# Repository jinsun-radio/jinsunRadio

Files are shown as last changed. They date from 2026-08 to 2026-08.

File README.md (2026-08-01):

# jinsun-radio（金孫收音機）

給獨居與失能長者的近端 AI 陪伴與社區互助派遣系統。

以長輩熟悉的收音機作為入口，打開、按下、說話——零學習成本。平常資料在地處理、不監控、不上雲；只有主動求助或授權週報才啟用 ASR／LLM／TTS。當長者提出需求或發生緊急狀況，系統會通知家人並媒合附近志工、物業、照服員，以時間銀行回饋，形成可追蹤、可派遣、可回報的照顧閉環。

> 一句話定位：不是讓長輩學會用 App，而是讓 AI 長得像他本來就會用的收音機。

2026 AI 創新獎・組別二：智慧照護與居家健康（Smart Care & Home Health）參賽提案。

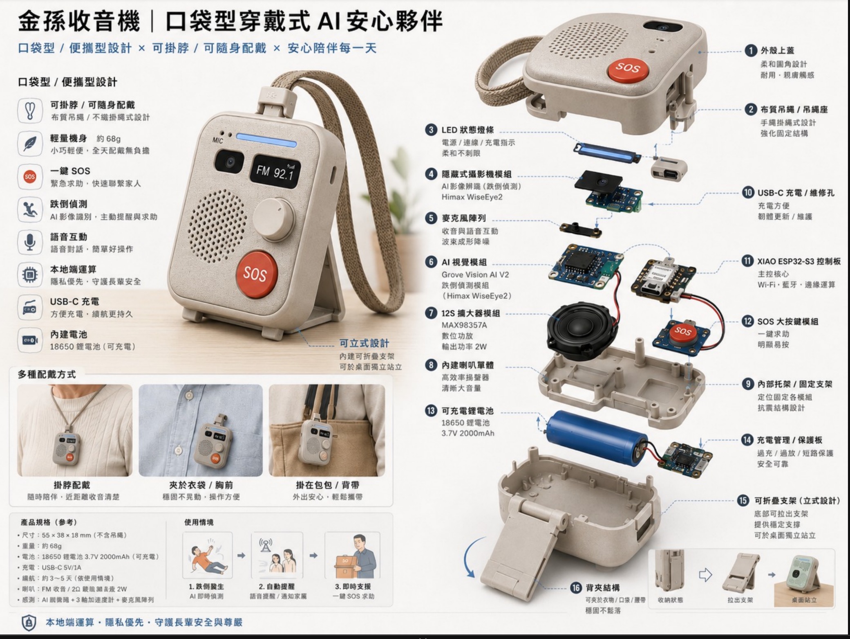
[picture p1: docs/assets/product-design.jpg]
金孫收音機｜口袋型穿戴式 AI 安心夥伴


> ⚠️ 硬體型態迭代中：目前有兩個版本的設計圖並存——`docs/assets/system-architecture.jpg`（桌上型收音機，主控為 Realtek AmebaPro2）與上圖（口袋型穿戴式，主控為 XIAO ESP32-S3）。以哪個為準尚待確認，見下方「技術架構」。

## 核心場景

- **大按鈕 SOS**：一按直接求助，不必解鎖打字
- **跌倒／久臥偵測**：近端視覺＋麥克風陣列偵測異常，語音確認「有沒有撞到？」
- **語音求助／代辦**：長輩以自然語言（含台語）說出需求，如「我想買牛奶跟雞蛋」
- **吃藥／復健提醒**：可由兒女預先錄音
- **安心週報**：授權後由 AI 摘要活動、提醒、異常、互動狀況
- **社區派遣**：偵測到緊急狀況 → 通知監護人 → 派送附近志工／物業／照服員 → 回報 ETA → 到場回報「已安全」

## 角色與軟體類型

| 角色 | 需要看到／做到什麼 | 軟體類型 |
|---|---|---|
| 長輩 | 不需要 App，只需要收音機：跌倒偵測相機＋聲音偵測＋語音播報（是否需要幫助／還有多久會到）＋ SOS 時 TTS | 嵌入式裝置，零學習成本 |
| 家屬 | 掌握老人家即時狀態、接收緊急通知 | Flutter App（跨 Android／iOS） |
| 志工 | 看到老人家需要什麼物資、接單去採買／到場確認安全 | Flutter App |
| 管理介面後台（社工／我們） | 所有長輩即時狀態的 dashboard，需可匯出 Excel 以符合政府申報需求 | Web（App 亦可） |

## 技術架構：感知 → 決策 → 行動 → 回報

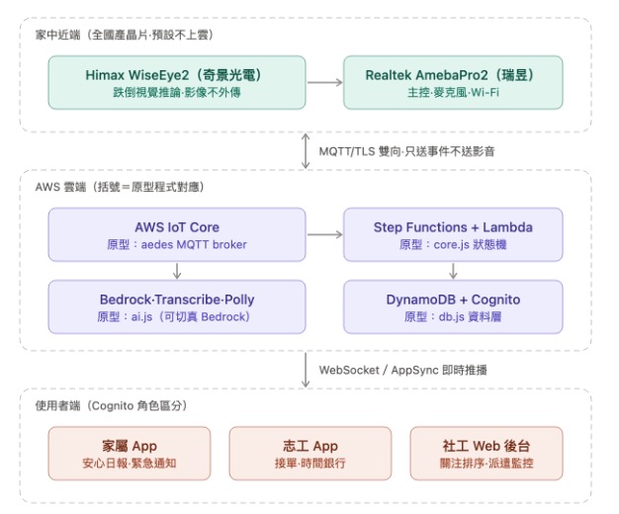
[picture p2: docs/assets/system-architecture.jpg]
系統架構圖


- **感知層（長輩端裝置，全國產晶片，預設不上雲）**：Himax WiseEye2（奇景光電，跌倒視覺推論，透過 Grove Vision AI V2／XIAO ESP32-S3 兩種硬體型態都在評估中，見上方警示）＋麥克風陣列；裝置與雲端之間僅透過 MQTT/TLS 傳送事件，不傳影音
- **決策層（AWS 雲端）**：AWS IoT Core 接事件 → Step Functions + Lambda 做事件分級與逾時升級判斷 → Bedrock／Transcribe／Polly 處理 ASR／LLM／TTS → DynamoDB + Cognito 做資料層與角色權限
- **行動層**：裝置端語音對講與安撫回應（「已經幫你叫人，預計 6 分鐘內到」）＋透過 WebSocket／AppSync 即時推播給家屬 App／志工 App／社工 Web 後台，媒合志工到場確認安全（Physical AI in the Loop，類似 Uber 的派工與 ETA 回報）

完整架構圖與跌倒偵測事件流程（sequence diagram）見 [`docs/architecture.md`](docs/architecture.md)。

技術落地路線：Himax WiseEye2 → 延伸至 Kneron + Andes RISC-V 國產邊緣 AI 生態。

## 隱私與資安設計

| 模式 | 運作 | 內容 |
|---|---|---|
| 平常模式 | 近端運作 | 提醒、關鍵字偵測、跌倒判斷；原始影音不上雲 |
| 主動模式 | 需要時才上雲 | 求助、叫人、家屬授權週報；ASR／LLM／TTS 處理 |
| 對講模式 | 可被看見、可被拒絕 | 家人不能偷聽；長輩可說「好」或「不要」 |

設計底線：長輩永遠知道自己何時被連線、何時被求助、資料何時離開家。

## 硬體規格（口袋型穿戴版本，參考）

| 項目 | 規格 |
|---|---|
| 尺寸 | 55 × 38 × 18 mm（不含吊繩） |
| 重量 | 約 68g |
| 電池 | 18650 鋰電池 3.7V 2000mAh（可充電） |
| 充電 | USB-C 5V/1A |
| 續航 | 約 3–5 天（依使用情境） |
| 喇叭 | FM 收音，輸出功率 2W |
| 感測 | AI 視覺辨識（跌倒偵測）＋ 3 軸加速度計 ＋ 麥克風陣列 |
| 配戴方式 | 掛脖、夾於衣物／口袋、掛包包背帶；內建可折疊支架可桌面立式擺放 |

主要模組：外殼上蓋、布質吊繩、LED 狀態燈條、隱藏式攝影機模組（Himax WiseEye2 跌倒視覺辨識）、麥克風陣列、Grove Vision AI V2 視覺模組、MAX98357A 數位功放、內建喇叭、XIAO ESP32-S3 控制板（主控／Wi-Fi／藍牙／邊緣運算）、SOS 大按鍵模組、可充電鋰電池與充電保護板、可折疊立式支架、背夾結構。完整零件圖見上方產品外觀圖。

## Repo 結構

```
jinsun-radio/
├── docs/           系統架構、事件流程圖
├── firmware/       長輩端裝置韌體（Himax WiseEye2 + Realtek AmebaPro2）
├── cloud/          雲端後端（AWS IoT Core / Step Functions / Bedrock / DynamoDB）
├── apps/
│   ├── family_app/     家屬 App（Flutter）
│   └── volunteer_app/  志工 App（Flutter）
└── admin/          管理介面後台（社工 Web dashboard）
```

## 快速啟動（Phase 1 薄閉環 demo）

三端皆為 Flutter 專案，資料層為 `jinsun_core` 的 `MockBackend`（in-app mock，無真後端）。iOS／Android 工具鏈尚未備齊時，用 `-d chrome` 或 `-d macos` 即可跑。

```bash
# 家屬 App
cd apps/family_app && flutter pub get && flutter run -d chrome

# 志工 App
cd apps/volunteer_app && flutter pub get && flutter run -d chrome

# 社工後台（web，含下載 Excel）
cd admin && flutter pub get && flutter run -d chrome

# 核心狀態機測試（20 秒升級、派遣生命週期、點數）
cd apps/packages/core && flutter test
```

開啟後按右下角「模擬收音機」觸發事件：
- **疑似跌倒** → 20 秒未回應自動升級 → 通知＋開派遣單（家屬端有虛擬志工自動接單回 ETA）
- **SOS** → 立即開緊急派遣單
- **物資需求** → 志工端可接單採買、回報送達

各端功能與範圍見子專案 README；spec 與拍板決策見 [`docs/requirements/phase1-mvp.md`](docs/requirements/phase1-mvp.md)。

## 專案狀態

Phase 1 薄閉環已實作（2026-07-11）：`jinsun_core` 狀態機＋家屬／志工／社工三端可跑、有測試。`cloud/` 與 `firmware/` 尚未動工，三端目前各自獨立模擬（跨裝置同步待 Phase 2 真後端）。詳細背景與完整企劃書內容請見團隊內部文件。

技術落地路線圖（Phase 1–4）：
1. Web／PWA ＋ 收音機外殼 mockup（服務閉環可展示）
2. Himax WiseEye2 近端影像／語音偵測驗證
3. 串接社區物業、照服單位、地方政府、時間銀行
4. 導入獨居老人服務、關懷據點、銀髮宅、智慧社區

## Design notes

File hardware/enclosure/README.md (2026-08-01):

# 長輩端收音機外殼（HUB8735 Ultra smart speaker enclosure）

長輩端裝置的實體外殼：參數化 CAD 原始碼（build123d / Python）＋可直接列印的 STL / 3MF。
韌體在 `firmware/`，硬體與雲端的整合契約在 `docs/requirements/hardware-integration.md`。

外形：直立式圓潤方塊，外徑約 **96 × 115.5 × 56 mm**（W × H × D，含磁吸背板與立架翻片），
單位一律 mm。世界座標：+X 右（正面視角）、+Y 向後、+Z 上；原點 X 置中、Z=0 在外底面、
正面外表面在 Y=−23。

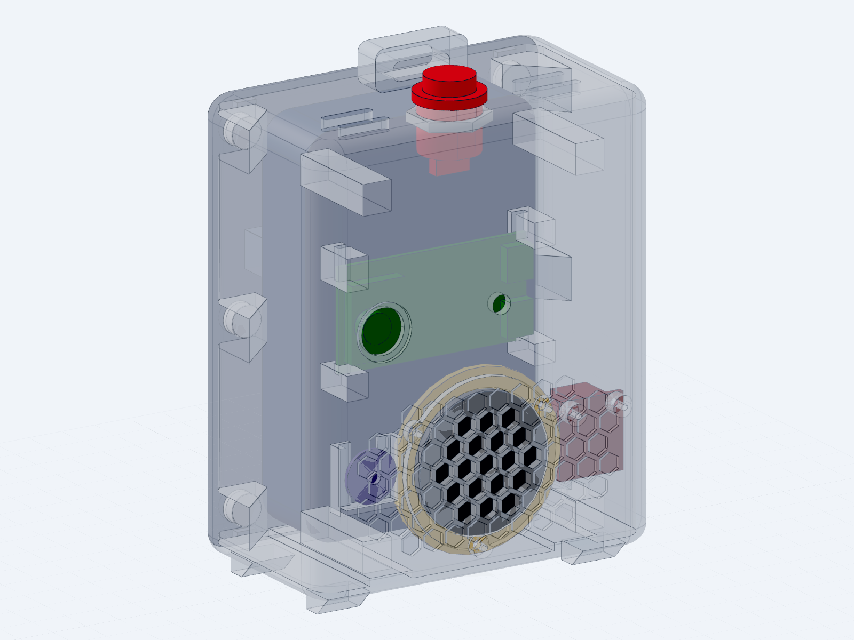
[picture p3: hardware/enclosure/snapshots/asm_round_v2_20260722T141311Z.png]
組裝件


## 檔案結構

```
hardware/enclosure/
├── speaker_design.py                參數與全部零件的 make_*() 幾何（唯一 source of truth）
├── hub8735_speaker_assembly.py      完整標註組裝件（含 mating datums）
├── shell_print.py                   列印件：主殼
├── back_panel_print.py              列印件：磁吸背板
├── speaker_clamp_print.py           列印件：喇叭壓環
├── stand_flap_print.py              列印件：折疊立架／背夾
├── assembly_test.py                 干涉與置入路徑稽核（改版後必跑）
├── *.step                           上列各 .py 產生的 STEP（交付物，進版控）
├── print/                           切片用 STL / 3MF
├── snapshots/                       定版設計截圖
└── reference/speaker-grille.stl     正面蜂巢格柵的造型參考件
```

**只改 `.py`，不要手改 `.step`。** `.step` / `print/*` 都是由 `.py` 產生的輸出。

## 五個列印件

| 檔案 | 說明 | 列印方向 / 材料 |
|---|---|---|
| `shell_print` | 主殼：正面蜂巢格柵、相機窗、喇叭座、麥克風通道、擴大機柱、行動電源導軌、頂部按鈕孔與背帶橋 | 正面朝下貼床（切片前繞 X 轉 −90°），內部特徵全部往上長 |
| `back_panel_print` | 磁吸背板：6 顆磁鐵、4 條對位唇、立架鉸鏈耳座 | 外面朝下貼床（唇朝上） |
| `speaker_clamp_print` | 喇叭壓環，壓住 36 mm 喇叭法蘭 | 平放；3× M2×5 **沉頭**自攻螺絲鎖進殼體柱 |
| `stand_flap_print` | 折疊立架／背夾，鉸接在背板上（Ø3 卡榫扣進耳座），開到 ~35° 讓機身後仰 ~12° | 平放（外面朝下）；**建議 PETG**，夾持需要彈性 |
| `hub8735_speaker_assembly` | 不列印，是驗證與展示用的完整組裝件 | — |

## 內部元件（尺寸皆為實測／查證，非估計）

- **HUB8735 Ultra**：53 × 27 mm PCB、模組厚 8.8 mm。側裝（53 mm 橫置），PCB 平行正面牆，
  鏡頭穿過正面 Ø17 窗。板子由上往下滑入兩支 C 形溝槽塔，**只夾四個短邊角**（長邊有焊排）。
  USB-C 朝 +X，內部留約 28 mm 插頭空間。板背若插排針，與行動電源僅剩約 0.9 mm——
  **杜邦母頭裝不下，要焊線或用直角接頭**。
- **喇叭**：Ø36 ±0.4 / 深 17 ±0.5 / 法蘭 2.7 ±0.3，3 W 4 Ω。淺座環定位 ＋ 壓環固定。
- **麥克風**：INMP441 breakout（**圓形 Ø14**），貼正面牆的 C 形凹槽，Ø3 導音孔穿牆（底進音 MEMS）。
- **擴大機**：GY-MAX98357A（18 × 20，上緣端子台），鎖在兩支 M2 柱上（間距 13 mm，**實板需複驗**），元件面朝後。
- **行動電源**：MD-BP075-Qi，104 × 65 × 19.5 mm、約 200 g、10000 mAh。直立靠背板，
  由地軌＋前擋柱＋磁鐵柱內面定位，拆背板即可更換；底部留充電線槽。
- **按鈕**：16 mm 防水鈕，M16×1.0、body flats 15.0、帽 Ø13、全長 24.8。頂板孔 Ø16.2 帶 15.2 防轉平邊。
- **磁吸背板**：12 顆 Ø8×3 圓磁（殼側 6 顆凹陷 0.8、板側 6 顆凸出 0.8，互相自動對位）。
  **磁鐵要黏牢，且注意極性。**

BOM 五金：3× M2×5 沉頭自攻（喇叭壓環）、2× M2 自攻（擴大機）、12× Ø8×3 圓磁鐵、
16 mm 按鈕 ×1、背帶織帶（頂部 16 × 5 穿帶孔）。

## 幾個不能亂動的設計約束

改幾何前先讀這幾條，都是 `assembly_test.py` 的置入路徑掃掠稽核逼出來的：

1. **只夾三角**：右上角不能有夾塊，否則抽板時卡住 USB-C 凸出。
2. **上排夾塊止於 Z 82.5**：再高則板子由上往下放不進去（頂到天花板）。
3. **左上夾塊內面 −34.6**：讓出相機模組的掃掠通道。
4. **行動電源左上擋點是天花板懸吊的 45° 倒角肋（Y ≥ −4.5）**，不能改成正面牆立柱——會擋住板子的抽出路徑；右上維持立柱。
5. **頂部圓角 ≤ 6**（≥7 會破到內部天花板角落）；喇叭壓環在 X=−22.2 有一段平邊讓開麥克風通道。
6. **格柵底孔要停在凹槽底面下方 ≥1 mm**，否則正面會穿孔。
7. 背板對位唇貼在腔體地板／天花板的 X 34–42.9（貼側牆會撞到後腔圓角）。

**任何佈局改動後都要重跑 `assembly_test.py`。**

## 工具鏈設定

CAD 技能（`cad` / `cad-viewer` / `gcode` 等）已 vendored 在 repo 根目錄的 `.agents/skills/`，
版本鎖在 `skills-lock.json`。Python 環境不進版控，第一次要自己建：

```bash
# 在 repo root
uv venv --python 3.12 .venv          # 或 python3.12 -m venv .venv
.venv/bin/pip install -r .agents/skills/cad/requirements.txt   # cadpy(editable) + playwright
.venv/bin/python -m playwright install chromium --only-shell   # snapshot 需要
```

已驗證版本：Python 3.12、build123d 0.11.1。

## 常用指令

在 `hardware/enclosure/` 底下執行（路徑是相對於 cwd 解析的）：

```bash
R=../..   # repo root

# 由 .py 重新產生 STEP（＋viewer 用的 GLB 快取）
$R/.venv/bin/python $R/.agents/skills/cad/scripts/step shell_print.py
$R/.venv/bin/python $R/.agents/skills/cad/scripts/step hub8735_speaker_assembly.py

# 匯出切片用 mesh
$R/.venv/bin/python $R/.agents/skills/cad/scripts/step shell_print.py --stl print/shell_print.stl

# 幾何檢查
$R/.venv/bin/python $R/.agents/skills/cad/scripts/inspect refs shell_print.step --facts --planes --positioning

# 視覺檢查（--job 批次模式會靜默失敗，一次只跑一個 --input/--output）
$R/.venv/bin/python $R/.agents/skills/cad/scripts/snapshot --input shell_print.step --output snapshots/shell.png

# 干涉／置入路徑稽核
$R/.venv/bin/python assembly_test.py

# 3D viewer（預設 port 4178）
node $R/.agents/skills/cad-viewer/scripts/viewer/backend/server.mjs
```

完整設計歷程與中間迭代截圖留在原始 CAD repo（`../cad`，`hub8735_speaker/`），這裡只保留定版。

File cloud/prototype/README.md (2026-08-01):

# cloud/prototype · 語音多 Agent server（本地原型）

硬體只做「喚醒 + 錄音 + ASR → 文字」；**所有意圖判斷、對話、急救與需求決策都在這個 server**。
設計成介面可直接切換成 AWS 服務（見 [`../../docs/architecture.md`](../../docs/architecture.md)、
[`../../docs/requirements/voice-agent-server.md`](../../docs/requirements/voice-agent-server.md)）。

## 資料流

```
硬體(喚醒+ASR) → POST /voice {device_serial,text}
      → Orchestrator
         ├─ 急救對話進行中？ → Emergency Agent（吃掉「我沒事」/後續回應）
         ├─ Intent Agent 分類（rule 快路徑優先，未命中才問 Bedrock）
         │    emergency → Emergency Agent（逾時階梯 → 升級派遣）
         │    need      → Needs Agent（建 supply 派遣單）
         │    device    → Device Agent（音量/停止…）
         │    general   → Conversation Agent（帶 Memory）
         └─ Response Generator → { reply, intent, action }
      → 硬體 TTS 播 reply；action.command 由硬體執行
```

Emergency / Needs 的決策會寫進既有 Supabase（`radio_events` + `dispatch_tasks`），
**自動觸發家屬 App／志工 App／社工後台的即時推播**——不另建通知系統。

## 跑起來（零設定、離線可跑）

```bash
cd cloud/prototype
npm test          # 黃金時間鏈路合約測試（假計時器，秒過）
npm start         # 啟動 server（預設 mock LLM + dry-run 派遣）

curl -s localhost:8787/voice -d '{"device_serial":"JS-0001","text":"我跌倒了"}'
curl -s localhost:8787/voice -d '{"device_serial":"JS-0001","text":"我想買牛奶跟雞蛋"}'
```

不填任何金鑰時：LLM 走 mock（規則化回覆）、派遣走 dry-run（印 log），狀態機與測試照跑。

## 端到端測試：硬體發聲 → server → 三端亮起

目標：證明「裝置上報 → server 處理 → 寫進 Supabase → 家屬/志工/社工三端即時亮」整條通。

**關鍵前提**：server 要用 Supabase **SERVICE key**（secret，非 anon）才寫得進 `dispatch_tasks`。
用 anon key 只能寫 `radio_events`、寫不了派遣單 → 志工端不會出現接單。

```bash
cd cloud/prototype
npm i @supabase/supabase-js          # 讓 dispatch 能真的寫 Supabase

# 終端 A：啟動 server（填 service key → 啟動日誌要顯示 dispatch=live）
SUPABASE_SERVICE_KEY=<你的-service-key> EMERGENCY_WAIT1_MS=4000 EMERGENCY_WAIT2_MS=4000 npm start

# 終端 B：即時盯著 Supabase（不用開三個 App 也能確認寫進去了）
npm run watch
```

然後**模擬硬體**（或用真裝置對 `/voice` 發同樣的請求）：

```bash
# ① 實體 SOS 鍵 → 立即升級（終端 B 會馬上冒出 sos/escalated + emergency 待接單，長輩轉🔴）
curl -s localhost:8787/voice -d '{"device_serial":"JS-0001","event":"sos"}'

# ② 語音「我跌倒了」→ 問診 → 沒回應 → 約 8 秒後升級（用上面的 WAIT 環境變數縮短）
curl -s localhost:8787/voice -d '{"device_serial":"JS-0001","text":"我跌倒了"}'

# ③ 物資需求「我想買牛奶跟雞蛋」→ 立即出現 supply 待接單
curl -s localhost:8787/voice -d '{"device_serial":"JS-0001","text":"我想買牛奶跟雞蛋"}'
```

**驗收點**：
1. `npm run watch` 的「最新事件／派遣單」冒出新列、長輩燈號變色 → **server→Supabase 通**。
2. 打開家屬 App（該長輩收到緊急通知）、志工 App（出現待接單）、社工後台（dashboard 轉🔴）
   → **Supabase→三端推播通**。
3. 真裝置測下行：裝置訂閱 `jinsun/JS-0001/cmd`，急救逾時後應收到 speak 指令並發聲。
   瀏覽器模擬控制台仍走 `GET /commands` 長輪詢（enqueue 扇出，兩通道都會收到同一筆指令）。
   broker 有兩種型態，看 `/health` 的 `mqtt` 欄位確認目前模式：

   | 模式 | 怎麼啟動 | 裝置／對測連哪 |
   |---|---|---|
   | `live`（內嵌 aedes，本機開發） | `npm start`（預設，`MQTT_PORT` 可改埠、`0`＝停用） | `mosquitto_sub -h <server IP> -t 'jinsun/JS-0001/cmd' -v` |
   | `client`（外部 broker，Render 部署） | `MQTT_URL=mqtts://mqttgo.io:8883 npm start` | `mosquitto_sub -h mqttgo.io -t 'jinsun/JS-0001/cmd' -v` |

   Render 這類 PaaS 只對外開 HTTPS(443)，內嵌 broker 的 1883 從公網進不來，所以改設 `MQTT_URL`
   讓 server 與裝置各自連上同一顆外部 broker 會合（topic／payload／QoS 契約完全相同）。
   沒裝 mosquitto 的話 `npx mqtt sub …` 等效。

> `device_serial` 要用資料庫既有的 `JS-0001/JS-0002/JS-0003`（seed 已綁 elder-1/2/3），
> 否則 trigger 反查不到 elder_id。

## 接真服務

複製 `.env.example` 為 `.env` 並填：

- `LLM_PROVIDER=bedrock` + AWS 憑證 → Intent/Needs/Conversation 走真 Amazon Bedrock（Claude）。
  需 `npm i @aws-sdk/client-bedrock-runtime`。
- `SUPABASE_SERVICE_KEY=...` → Emergency/Needs 真的寫派遣單、觸發三端推播。
  需 `npm i @supabase/supabase-js`。

## 檔案

| 檔 | 職責 | 正式對應 |
|---|---|---|
| `src/config/triggers.js` | **喚醒詞／急救詞／需求詞／裝置詞＋急救對話腳本與逾時階梯**（寫死在 server） | Lambda 設定／參數表 |
| `src/agents/intent.js` | 意圖分類（rule + LLM） | Bedrock |
| `src/agents/emergency.js` | 急救對話狀態機（黃金時間鏈路） | Step Functions |
| `src/agents/needs.js` | 需求解析 → 物資派遣單 | Bedrock + Step Functions |
| `src/agents/conversation.js` | 陪伴聊天（帶記憶） | Bedrock |
| `src/agents/device.js` | 裝置控制指令 | IoT Core 下發 |
| `src/agents/memory.js` | 長期記憶 | DynamoDB |
| `src/llm/bedrock.js` | LLM 可切換介面（mock/bedrock） | Bedrock Runtime |
| `src/dispatch.js` | 寫 Supabase 觸發三端 | Step Functions + AppSync |
| `src/orchestrator.js` | 路由大腦 | — |
| `src/server.js` | HTTP 入口 | API Gateway + Lambda |

> ⚠️ 改動 `triggers.js` 的急救腳本或 `emergency.js` 的逾時階梯，必跑 `npm test`——
> 那是「20 秒無回應必升級」的黃金時間合約。

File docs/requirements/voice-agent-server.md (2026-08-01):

# 雲端語音多 Agent Server

> 對象：長輩端「主動語音互動」的雲端大腦。原型見 [`cloud/prototype/`](../../cloud/prototype/)。
> 本文是需求／設計 single source；架構總覽同步在 [`architecture.md`](../architecture.md)。
> A2A 多 Agent 架構圖、flow 圖與 sequence diagram 見 [`voice-agent-a2a-flow.md`](voice-agent-a2a-flow.md)。

## 1. 這一層在整個系統的位置

金孫收音機已有一條成熟鏈路：**事件 → 分級 → 派遣 → 三端推播**（Supabase `radio_events` /
`dispatch_tasks`，家屬 App／志工 App／社工後台即時同步）。

語音 Agent Server 不是另起爐灶，而是**在這條鏈路前面加一個「語音入口」**：
把長輩說的話（跌倒、求救、口渴、想買東西、閒聊）翻譯成系統聽得懂的「事件／派遣單」，
再讓既有鏈路接手。閒聊與裝置控制則就地回覆、不進派遣。

```
長輩說話 → 硬體(觸發+錄音) → 雲端 ASR → 語音 Agent Server ──(緊急/需求)──▶ radio_events + dispatch_tasks ─▶ 三端推播
                                                    └──(閒聊/裝置)──▶ 回文字給硬體 → 雲端 TTS 發聲
```

## 2. 對「硬體只收音」流程的判斷（回答提問）

**方向正確；ASR 依實測韌體改走雲端服務，但進到本 server 的仍然只有文字。** 理由：

1. **符合本專案隱私鐵律**（`CLAUDE.md` 約束 1）：影像不外傳，語音只有長輩**主動觸發**的段落上雲。
   實測韌體是裝置把主動錄音上傳外部 ASR 服務轉文字、再把文字送上來；`POST /voice` 契約不變：
   只吃文字、本 server 不開音檔端點。ASR 服務屬裝置側的前置依賴（硬體對接契約見
   [`hardware-integration.md`](hardware-integration.md)）；device-side STT 改列未來隱私強化方向。
2. **喚醒詞與急救詞要雙層**：
   - 裝置端本地有一組**離線喚醒/求救詞**（喊「救命」時就算網路不好也要能觸發本地燈號/鈴聲）。
   - 雲端再有一份**權威觸發表**（本文第 3 節），做最終分類與對話。兩者內容可重疊，職責不同。
3. **計時器（20 秒無回應升級）必須放雲端**，不能放硬體或 App。
   目前 demo 的升級計時器跑在 Flutter App 內（`SupabaseBackend`），App 一關就失效；
   正式版要由這個 Server 的 Emergency Agent（→ Step Functions）持有，才守得住黃金時間合約。

一句話：**硬體＝耳朵＋嘴巴（收音、觸發、播放、燈號、SOS 鍵，ASR/TTS 呼叫雲端服務）；雲端＝大腦（分類、對話、決策、計時、派遣）。**

## 3. Server 端寫死的觸發表（Rule-based）

實作於 [`cloud/prototype/src/config/triggers.js`](../../cloud/prototype/src/config/triggers.js)。
這層不進 LLM：快、穩、可審計；命中即定案，省一次模型呼叫。

### 3.1 喚醒詞 Wake Words
品牌名可調（預設「小金孫」）：

`小金孫`、`金孫`、`嘿金孫`、`金孫你好`、`阿金`、`救命`、`help`、`sos`、`有人嗎`

### 3.2 高優先急救詞 Emergency（→ Emergency Agent，不等 LLM）
`救命`、`救我`、`快來人`、`我跌倒/跌倒了/摔倒`、`起不來/爬不起來/站不起來`、
`好痛/很痛/不舒服`、`喘不過氣/不能呼吸/呼吸困難`、`胸口痛/心臟`、`流血`、`昏倒/頭暈/暈倒`

### 3.3 日常需求詞 Need（→ Needs Agent）
| 說法 | 建立的代辦 |
|---|---|
| 想喝水／口渴 | 喝水 |
| 餓了／肚子餓／想吃飯 | 吃飯 |
| 要吃藥／忘記吃藥 | 吃藥提醒 |
| 要上廁所 | 如廁協助 |
| 睡不著／失眠 | 休息 |
| 叫家人／找兒子女兒 | 聯絡家人 |
| 叫看護／找志工／需要幫忙 | 生活協助 |
| 我想買 X 跟 Y | 由 Needs Agent 抽出品項 → 物資派遣單 |

### 3.4 裝置控制詞 Device（→ Device Agent）
`大聲/聽不清楚` → volume_up；`小聲/太吵` → volume_down；`關掉/安靜/別說了` → stop_speak；`再說一次` → repeat

### 3.5 解除詞 Stand-down（急救對話中）
`我沒事`、`沒事`、`沒關係`、`不用`、`好了`、`不痛了`、`我很好`

## 4. 急救對話腳本與逾時階梯（黃金時間合約）

長輩「主動」喊救命＝已在求救，確認窗口要短。腳本與秒數寫在 `triggers.js` 的 `EMERGENCY_SCRIPT`，
狀態機在 [`emergency.js`](../../cloud/prototype/src/agents/emergency.js)：

| 步驟 | 對長輩說（TTS） | 等待 | 無回應則 |
|---|---|---|---|
| 觸發 | 「我聽到您說『救命』了，我在這裡。請問您現在還好嗎？可以回我一聲嗎？」 | 10s | 進下一步 |
| 逾時① | 「我沒有聽到您的聲音。如果您沒事，請說『我沒事』；需要幫忙，說一聲就好。」 | 12s | **升級派遣** |
| 升級 | 「別擔心，志工已經在路上，大約 N 分鐘到，我會一直陪著您。」 | — | — |
| 解除 | 長輩說「我沒事」→「好，聽到您沒事我就放心了，有需要叫我『金孫』就好。」 | — | 結束、不派遣 |

- 總確認窗口 ≈ 22 秒，守住約束「疑似跌倒 20 秒內升級」的精神；秒數可在 config 調。
- **升級動作** = 寫 `radio_events(status=escalated, severity=emergency)` + `dispatch_tasks(kind=emergency)`
  → 觸發家屬推播＋志工派遣單（既有鏈路）。
- 相機偵測到的「疑似跌倒」仍走既有 20 秒單階梯；本階梯是給「語音主動求救」用。

## 5. 六個 Agent 職責

| Agent | 進 LLM？ | 職責 | 輸出 |
|---|---|---|---|
| Intent | 是（rule 未命中才問） | 只分類：emergency/need/device/general | 一個標籤 |
| Emergency | 對話 | 逾時階梯、安撫、升級派遣 | TTS 文字 + 升級 |
| Needs | 是 | 抽出物資／代辦品項 | TTS 文字 + supply 派遣單 |
| Conversation | 是 | 陪伴聊天，帶記憶 | TTS 文字 |
| Memory | 輕量（可 LLM） | 記住反覆狀態/偏好 | 供 Conversation 呼應 |
| Device | 否 | 音量／停止／重說 | 裝置指令 |

Orchestrator（[`orchestrator.js`](../../cloud/prototype/src/orchestrator.js)）：
先看「是否在急救對話中」，再 rule 快路徑＋Intent 分類，最後分派。安全預設：**急救對話進行中，
長輩的後續發言（非『我沒事』）一律留在急救情境**，不會被誤切成聊天。

## 6. AWS 對應

| 原型模組 | AWS 正式服務 |
|---|---|
| `server.js`（HTTP /voice） | API Gateway + Lambda（或 IoT Core rule → Lambda） |
| `agents/intent|needs|conversation` + `llm/bedrock.js` | **Amazon Bedrock（Claude）** |
| `agents/emergency.js`（逾時階梯狀態機） | **Step Functions**（含 wait state） |
| `agents/memory.js` | DynamoDB |
| `dispatch.js`（寫事件/派遣） | Step Functions + 既有資料層；即時推播 AppSync |
| Device Agent 指令下發 | IoT Core（MQTT）→ 裝置 |
| 通知家屬/志工 | 既有三端推播鏈路（不重造） |

Agent 間若要非同步解耦，用 EventBridge / SQS；監控用 CloudWatch。

## 7. 待決定

- **品牌／喚醒詞**：目前預設「小金孫」，需產品定案（影響裝置端本地喚醒模型訓練）。
- 逾時秒數（10s / 12s）需場域驗證微調。
- ~~裝置端是否具備本地 ASR 算力~~ → **已定案：ASR 走雲端服務**（實測用 faster-whisper Breeze-ASR-26，見第 2 節、`hardware-integration.md`）；device-side STT 改列未來隱私強化方向。
- Cognito 角色與這個 Server 的認證串接（長輩裝置以 device_serial 綁定 elder）。

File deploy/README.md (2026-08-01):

# 部署與展示

系統有兩塊，部署位置不同：

| 元件 | 位置 | 為什麼 |
|---|---|---|
| 家屬／志工／社工 三端（Flutter Web） | **AWS S3 + CloudFront**（靜態）或 Vercel | 純靜態檔，給網址即可用 |
| 語音 Agent server（`cloud/prototype`） | **AWS ECS Fargate + ALB**（常駐）或 Render | 20 秒升級計時器、`/commands` 長輪詢＋下行佇列、進度播報 Realtime 訂閱都要常駐程序，serverless 會全壞 |

> ⭐ **推薦方案：AWS（ECS Fargate + S3/CloudFront）**——見下方「方案 A」。
> Render + Vercel 方案仍保留作為備選（見「方案 B」）。

> 三端的資料連動走 Supabase（已在雲端），所以就算不部署 server，三端上 Vercel 後也能靠 Supabase 即時同步。
> 只有**社工後台的「硬體模擬」頁**與**語音大腦（Bedrock／急救鏈路／進度播報）**需要 server。

---

## 方案 A：AWS ECS Fargate + S3/CloudFront（推薦）

以 Kiro 為主要開發工具，全程用 CLI 完成，不需要進 AWS Console。

### 前提

- 已安裝 `aws` CLI（[安裝](https://docs.aws.amazon.com/cli/latest/userguide/getting-started-install.html)）
- 已安裝 `docker`（Docker Desktop）
- AWS credentials 設好（見下方「設定 credentials」）

### 設定 AWS credentials

```bash
# 互動式引導
bash deploy/aws/setup-credentials.sh

# 或者——Workshop 一時憑證：從 Dashboard 複製 export 貼進 terminal
export AWS_ACCESS_KEY_ID="ASIA..."
export AWS_SECRET_ACCESS_KEY="..."
export AWS_SESSION_TOKEN="..."
export AWS_DEFAULT_REGION="us-west-2"

# 或者——IAM 長期憑證：
aws configure
```

### ① 部署語音 server（ECS Fargate，常駐）

```bash
bash deploy/aws/deploy-server.sh
```

腳本自動完成：
1. 建立 ECR repository（若不存在）
2. Docker build（ARM64，Apple Silicon 原生、快速）
3. Push image 到 ECR
4. 建立 ECS Cluster、IAM role、Security Groups
5. 建立 ALB + Target Group + Listener
6. 註冊 Task Definition（Fargate ARM64 / Graviton）
7. 建立 / 更新 ECS Service

部署完成後會得到 ALB URL（如 `http://jinsun-alb-xxx.us-west-2.elb.amazonaws.com`），記下來。

**目前正式 ALB URL：**
```
http://jinsun-alb-1316925531.us-west-2.elb.amazonaws.com
```

### ①.5 ⚠️ 讓 https 網頁能打到 server（CloudFront https 前置，必做）

ALB 只有 **HTTP**，但網頁部署在 https（Vercel／CloudFront）。https 頁呼叫 http server
會被瀏覽器擋成 **mixed content** —— 家屬「立即提醒」按鈕、長輩收音機的 `/commands`
長輪詢、`/voice`、`/tts` 全部會失敗。所以 server 也要一個 https 入口：

```bash
# 前提：deploy-server.sh 已跑過（ALB 在、/remind 已上 ECS）
bash deploy/aws/setup-server-cloudfront.sh
```

會建一個 CloudFront distribution 前置 ALB，印出 `https://xxxx.cloudfront.net`。
約 5–10 分鐘 Deployed 後，**這個 https 網址才是網頁要用的 `SERVER_URL`／`SIM_BASE`**。
（API 專用：不快取、轉發所有 method/header/query/body、回源逾時 60 秒撐得住長輪詢。）

> 吃藥提醒鏈路：家屬 App 按「立即提醒」→ `POST $SERVER_URL/remind`
> → server `enqueue` 扇出 → MQTT `jinsun/{serial}/cmd`（真收音機發聲）＋長輪詢
> （模擬器／長輩網頁 `GET /commands` 念出來）。真收音機那條與 server 是否 https 無關
> （server 是 MQTT client 連 `mqttgo.io`）。

### ② 部署三端 Flutter Web（S3 + CloudFront）

```bash
export SERVER_URL=http://jinsun-alb-1316925531.us-west-2.elb.amazonaws.com
bash deploy/aws/deploy-web.sh
```

腳本自動完成：
1. 建立 3 個 S3 bucket（靜態網站託管）
2. Flutter build web（admin 帶 `--dart-define=SIM_BASE=$SERVER_URL`）
3. Sync 到 S3（含 cache-control 策略）
4. CloudFront cache invalidation（如有設定 distribution ID）

### 可調環境變數

| 變數 | 預設值 | 說明 |
|---|---|---|
| `AWS_REGION` | us-west-2 | 部署 region |
| `ECR_REPO` | jinsun-voice-server | ECR repo 名 |
| `CLUSTER_NAME` | jinsun-cluster | ECS cluster 名 |
| `SERVICE_NAME` | jinsun-voice-server | ECS service 名 |
| `BUCKET_FAMILY` | jinsun-family-web | 家屬 S3 bucket |
| `BUCKET_VOLUNTEER` | jinsun-volunteer-web | 志工 S3 bucket |
| `BUCKET_ADMIN` | jinsun-admin-web | 社工 S3 bucket |
| `CF_DIST_FAMILY` | (空) | CloudFront Distribution ID |

### 設定檔參考

- `deploy/aws/apprunner.yaml`：ECS Fargate 宣告式設定（人讀用，非 CLI 直接吃）
- `deploy/aws/cloudfront-spa.json`：CloudFront 自訂錯誤頁（SPA fallback）
- `deploy/aws/setup-credentials.sh`：AWS credentials 設定引導

---

## 方案 B：Render + Vercel（備選）

### ① 先部署語音 server（Render，常駐）

`deploy/render.yaml` 已備好。Render Dashboard → New → **Blueprint** → 指到本 repo →
在 Dashboard 補三個機密環境變數：`AWS_ACCESS_KEY_ID`／`AWS_SECRET_ACCESS_KEY`（**用不會過期的 IAM 憑證**，非 workshop 一時憑證）、`SUPABASE_SECRET_KEY`。
部署好會得到一組網址，如 `https://jinsun-voice-server-mg1f.onrender.com`（記下來，下一步要用）。

> 只想先在本機 demo 又要公開網址：`brew install cloudflared && cloudflared tunnel --url http://localhost:8787`，
> 會得到一組臨時 https 網址（每次重開會變）。

### ② 再部署三端 Vercel（把 server 網址帶進去）

需要一組 Vercel token（vercel.com → Settings → Tokens → Create）：

```bash
export VERCEL_TOKEN=你的token
export SERVER_URL=https://jinsun-voice-server-mg1f.onrender.com   # ← 上一步的 server 網址
bash deploy/deploy-all.sh
```
`SERVER_URL` 會在 build 時透過 `--dart-define=SIM_BASE=` 注入 admin，讓「硬體模擬」頁打得到 server。
（家屬／志工不需要，它們只走 Supabase。）

會依序 build 並部署三個 App，各印出一組正式網址：

| App | 建議 project 名 | 給誰用 |
|---|---|---|
| 家屬 App | jinsun-family | 家屬（手機瀏覽器，可加到主畫面像 App） |
| 志工 App | jinsun-volunteer | 社區志工 |
| 社工後台 | jinsun-admin | 社工／管理者（電腦） |

Demo 參數：家屬 `?demo=1`（自動登入綁定）、`?demo=fall`（自動演跌倒）；
志工 `?demo=sos`；後台開 `#admin`。

## 「不是網站」的部分怎麼給別人看

| 交付物 | 形式 | 給別人看的方式 |
|---|---|---|
| 家屬／志工／社工三端 | Flutter Web | ← 部署 Vercel，給網址即可（本頁上方） |
| 家屬／志工手機 App（原生） | Flutter Android／iOS | Android：`flutter build apk` 給 .apk 安裝；iOS：TestFlight。展示用 Web 版即可，不必先上架 |
| 收音機（長輩端硬體） | 韌體＋裝置 | 拍 30 秒實機 demo 影片＋現場實機；規格見 `docs/HARDWARE_SPEC.md` |

> 對比賽 demo 而言，Web 版部署後給一條網址是最省事的方式：評審在自己的
> 手機上就能同時開三端操作，家屬 App 加到主畫面後全螢幕、與原生 App 幾乎
> 無異。原生 APK／iOS 上架留到真正落地推廣階段再做。

## 備註

- `deploy/vercel.json` 設定 SPA fallback（找不到實體檔的路徑回 index.html），
  部署時腳本會自動複製進各自的 `build/web`。
- Vercel 免費方案足夠 demo；三個 App 是三個獨立 project。
- 若偏好 Netlify：把 `build/web` 目錄拖進 Netlify Drop（app.netlify.com/drop）
  也能立刻得到網址，完全不用 CLI 或帳號設定。

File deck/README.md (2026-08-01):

# 金孫收音機 — 提案簡報 deck

2026 AI 創新獎提案簡報，純靜態網頁（HTML + CSS + vanilla JS），無需建置工具。

## 開啟／預覽

直接用瀏覽器打開 `index.html` 即可。若某些瀏覽器擋本機檔案讀取，改用本機伺服器：

```bash
cd deck && python3 -m http.server 8000
```

然後開 <http://localhost:8000>。

## 檔案結構

```
deck/
├── index.html      投影片內容（改文字／新增頁面主要動這裡）
├── style.css       簡報樣式
├── assets/         簡報框架：runtime.js（翻頁）、base.css、fonts.css、animations/
└── img/            所有情境圖與截圖
```

## 一起改的注意事項

- **改內容**：編輯 `index.html` 的各張 slide；改樣式動 `style.css`。`assets/` 是共用框架，非必要不動。
- **加圖**：放進 `img/`，用相對路徑 `img/xxx.png` 引用；請壓到 ~2MB 以下（現況最大約 2.3MB）。
- 簡報內三個 App 連結指向已部署的 CloudFront 網址（家屬／志工／社工後台），非本機資源。
- `.DS_Store` 已被 `.gitignore` 排除，勿手動加入。

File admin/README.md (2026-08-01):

# admin（管理介面後台）

給社工／營運團隊使用的即時 dashboard。

- **平台**：Web（App 亦可，優先做 Web）
- **角色**：社工／管理者
- **功能**：
  - 所有長輩的即時狀態總覽（正常／注意／緊急）
  - 事件關注排序、派遣監控
  - **匯出 Excel**：符合政府申報／稽核需求

詳見 [`../docs/architecture.md`](../docs/architecture.md) 與 [`../docs/requirements/phase1-mvp.md`](../docs/requirements/phase1-mvp.md)。

## 啟動方式

```bash
flutter pub get
flutter run -d chrome
flutter test
```

## 狀態

Phase 1 薄閉環：長輩即時狀態板（緊急→注意→正常排序）、事件紀錄表、派遣監控表、Excel 匯出（`excel` package，web 端點擊即下載 `.xlsx`）、demo 面板。技術棧選型 Flutter web（決策記錄見 `docs/requirements/phase1-mvp.md`）。資料層為 `jinsun_core` 的 `MockBackend`，無真後端。

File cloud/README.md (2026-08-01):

# cloud（雲端後端）

事件分級、決策派遣、資料層與角色權限，串起裝置端與三個使用者端。

## 服務

| 服務 | 用途 | 原型對應（規劃中，尚未動工） |
|---|---|---|
| AWS IoT Core | 接收裝置端 MQTT 事件 | aedes MQTT broker |
| Step Functions + Lambda | 事件分級、逾時升級、派遣狀態機 | core.js 狀態機 |
| Bedrock / Transcribe / Polly | ASR／LLM／TTS | ai.js（介面設計為可直接切換成真的 Bedrock） |
| DynamoDB + Cognito | 資料層、角色權限（家屬／志工／社工） | db.js 資料層 |

即時推播給使用者端透過 WebSocket / AppSync。

詳見 [`../docs/architecture.md`](../docs/architecture.md)。

## 狀態

尚未開始實作，先以本地原型（aedes / core.js / ai.js / db.js）驗證狀態機邏輯，之後再換成對應的 AWS 服務。

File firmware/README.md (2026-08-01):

# firmware（長輩端裝置）

收音機硬體端韌體。實測板為 **HUB8735 Ultra**（Realtek RTL8735B / AmebaPro2），語音互動 pipeline 已在此板實機跑通：**按鈕錄音 → 雲端 ASR → 雲端語音 Agent（`POST /voice`）→ 雲端 TTS → 喇叭播放**，並以 MQTT 常駐訂閱接收雲端下行指令。

程式碼：[`HUB-8735-Ultra-ASR-TTS.ino`](HUB-8735-Ultra-ASR-TTS.ino)

> 架構總覽與目標契約見 [`../docs/architecture.md`](../docs/architecture.md) 與
> [`../docs/requirements/hardware-integration.md`](../docs/requirements/hardware-integration.md)。
> 口袋型穿戴版（XIAO ESP32-S3）目前僅為設計概念，所有實測都在桌上型 HUB8735 Ultra 上進行。

## 已跑通的語音 pipeline（現況）

**上行（長輩主動觸發才錄音上雲）**

1. 長輩**按住按鈕 2 秒** → 播 `init.wav` 提示音 → 開始錄音（板載 PDM 麥克風，16kHz mono，AAC/MP4 暫存 SD 卡，最長 30 秒；**再按一下**或序列輸入 `stop` 提前結束）
2. 錄音結束 → 播 `wait.wav` 墊住處理時間 → 音檔上傳**雲端 ASR**（faster-whisper Breeze-ASR-26，OpenAI 相容 `/v1/audio/transcriptions`）→ 取得中文文字
3. 文字送**雲端語音 Agent server**（`POST /voice`，帶 `device_serial`）→ 雲端做意圖分類、起 20 秒升級計時、必要時開派遣單，同步回一句要立刻播的 `reply`＋選用的 `action.command`
4. 回覆文字送**雲端 TTS**（回傳 WAV URL）→ 裝置以 HTTPS 串流邊下載邊播放（MAX98357 I2S 功放）

序列埠輸入 `sos` / `fall` 可模擬 SOS 鍵與相機跌倒事件（走同一條 `POST /voice`，`event` 欄位），沒有實體按鈕與相機時也能跑完整條鏈路。

**下行（雲端主動找長輩說話）**

開機後以 MQTT 常駐訂閱 `jinsun/{serial}/cmd`（QoS 1），雲端的急救逾時階梯與志工進度播報就靠這條推過來：收到 `{"commands":[…]}` 後 `speak` 送 TTS 發聲、`device` 執行 `volume_up`／`volume_down`／`repeat`／`stop_speak`。連線設 Last Will（`jinsun/{serial}/status` = `offline`），後台的「裝置離線」顯示不需另做心跳。斷線以指數退避重連（1s→2s→…→30s），重連後重新訂閱並補發 `online`。

> 指令在 MQTT callback 裡只入佇列、回主迴圈才播——callback 內直接播 TTS 會卡住收訊迴圈導致 keep-alive 斷線，而 QoS 1 重連後 broker 會重送同一則，變成無限循環播報。

開機自檢：WiFi 連上後，SD 卡正常播 `ready.wav`（無檔案則合成上揚雙音）；SD 卡異常合成三聲低音警告。

## 硬體接線（HUB8735 Ultra）

| 元件 | 接法 |
|---|---|
| 觸發按鈕 | D9 ↔ GND（`INPUT_PULLUP`，按下 = LOW；D12 被 I2S 佔用、D13 是閃光燈 PWM，不可用） |
| MAX98357 I2S 功放 | BCLK→D24、LRC→D12、DIN→D11、SD_MODE→D10（同時佔用 D22/D23，板載按鈕不可用） |
| 麥克風 | 板載數位 PDM，`AudioSetting(3)`＝16kHz Mono Digital PDM（設成類比會錄到一片死寂，實測 -74dBFS） |
| SD 卡 | 錄音暫存 `test.mp4`；提示音 `ready.wav` / `init.wav` / `wait.wav` |

## 外部服務（常數寫在 .ino 開頭，可抽換）

| 用途 | 服務 |
|---|---|
| ASR | `llm-gateway.xcc.tw` `/v1/audio/transcriptions`，model `paulpengtw/faster-whisper-Breeze-ASR-26`（OpenAI/Groq 相容介面） |
| 語音 Agent（大腦） | `https://jinsun-voice-server-mg1f.onrender.com/voice`（Render；意圖分類、20 秒升級、派遣） |
| MQTT broker（下行） | `mqttgo.io:8883`（TLS，憑證鏈根 ISRG Root X1 已內嵌於 .ino） |
| TTS | `kws.oaselab.org` `/nutntweng/tts/aten/`（回 JSON 帶 WAV URL，再 GET 串流播放） |

原本的「直連 Google Gemini」已移除——直連 LLM 時雲端不知道有人在求救，長輩的話進不了急救狀態機。

## 已知限制／注意事項

- WiFi SSID/密碼與各服務 API key **硬編碼在 .ino 裡**——commit／公開前必須處理（目標：BLE 配網＋安全儲存）
- 開機以 `settimeofday` 強制設定系統時間來通過 SSL 憑證驗證（板子無 RTC/NTP）。
  ⚠️ **重燒韌體時必須把 `tv.tv_sec` 更新到接近當天**（`date +%s`）：mqttgo.io 用 Let's Encrypt
  的 90 天短效憑證，時間設得太早會被判「憑證尚未生效」而連不上 MQTT
- `lang=taigi` 目前**會被念成國語**——現接的 ATEN TTS 只有一種語音。雲端不做台語翻譯（`text`
  一律正常中文，`lang` 只是選語音的旗標），所以換到支援台語的 TTS 只要改 `requestTTS`。
  這是台語播報能否落地的關鍵未決項，韌體會在 log 明確標示而不是靜默忽略
- `stop_speak` 只能清空待播佇列，無法中斷正在播放的那一句（`playWavStream` 是阻塞的）
- MQTT 連線在長時間阻塞操作（TTS 播放）期間可能逾時斷線，靠退避重連復原；ASR 等待迴圈中已插入
  `mqttPump()` 維持連線
- 尚未實作：跌倒偵測相機（Himax WiseEye2）、「小金孫」喚醒詞與離線急救詞「救命」、BLE 配網

## 對測（不用實機）

`device_serial` 硬編碼在 .ino 開頭，預設 `JS-0001`。用 mosquitto 當假裝置即可驗下行：

```bash
mosquitto_sub -h mqttgo.io -t 'jinsun/JS-0001/cmd' -v     # 收雲端 push
curl -s https://jinsun-voice-server-mg1f.onrender.com/voice \
  -H 'content-type: application/json' \
  -d '{"device_serial":"JS-0001","text":"我跌倒了"}'      # 觸發問診→逾時階梯
```

完整契約與交接清單見 [`../docs/requirements/hardware-integration.md`](../docs/requirements/hardware-integration.md)。

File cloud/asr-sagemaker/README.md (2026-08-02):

# asr-sagemaker（中文 ASR endpoint）

把 [Breeze-ASR-26](https://huggingface.co/paulpengtw/faster-whisper-Breeze-ASR-26)（CTranslate2 fp16，
底為 whisper-large-v2 針對台灣國語微調）部署成 SageMaker 即時 endpoint，供語音 Agent server 做 ASR。

只服務「長輩主動求助／代辦」那段上雲的語音，符合架構約束 1 的隱私邊界——跌倒推論與關鍵字偵測仍在裝置端。

評估結論、實測數字與選型理由見
[`../../docs/requirements/asr-breeze-sagemaker.md`](../../docs/requirements/asr-breeze-sagemaker.md)。

## 啟動

```bash
cp .env.example .env        # 填 SAGEMAKER_ROLE_ARN
scripts/fetch-model.sh      # 抓 3.1GB 權重到 model/（gitignore，可重複執行續傳）
scripts/deploy.sh           # 上傳 + 建 endpoint，約 15 分鐘
scripts/test.sh samples/*.wav
scripts/teardown.sh         # 用完務必執行，GPU 機型持續計費
```

改了 `src/inference.py` 之後用 `scripts/redeploy.sh v2` 滾動更新——只重傳 code，
S3 上的 2.9GB 權重不動。

## 介面（OpenAI 相容）

主要契約與 OpenAI `/v1/audio/transcriptions` 一致——吃 `multipart/form-data`，
欄位 `file` / `model` / `language` / `prompt` / `temperature` / `response_format`
（`json` | `verbose_json` | `text`），回 OpenAI 形狀的 `{"text": …}`。

這樣設計是為了讓前面那層代理只需要「重新簽章、原封轉發」，不用解析或改寫 payload；
韌體現有打 XCC Gateway 的 multipart 也就能原樣流過去。

另外保留兩種原生用法：

- `audio/wav`（或任何 `audio/*`）：直接送音檔 bytes
- `application/json`：`{"audio_base64": "…", "initial_prompt": "…", "beam_size": 5, "vad_filter": true}`

`json` 格式除了 `text` 還會多回 `segments[] / language / duration / processing_ms`
（OpenAI 只保證 `text`，其餘是擴充欄位）。即時 endpoint payload 上限 6MB，
約等於 3 分鐘 16kHz mono 語音。

### prompt 與時間戳的取捨

`prompt`（= faster-whisper 的 `initial_prompt`）餵照護領域詞彙可修正同音字錯誤
（實測「血壓要」→「血壓藥」）。未指定時會套用 `ASR_INITIAL_PROMPT` 環境變數的預設詞彙，
所以呼叫端不傳也有基本保護。

⚠️ **代價是 `segments` 的時間戳會失準**——實測同一段 4.2 秒語音，不帶 prompt 時
`end` 是 4.56，帶 prompt 時塌成 0.02。這是 whisper 對 prompt 條件化的已知副作用，
**`text` 完全不受影響**。

對本專案來說這個交換划算：狀態機只吃 `text`，而同音字錯誤是安全風險。
若你的用途真的需要可信的時間戳，明確傳 `prompt=""` 關掉預設詞彙即可
（空字串是「明確關閉」，不會被預設值蓋回去）。

```bash
scripts/test.sh samples/*.wav                    # 原生 JSON 介面 + 延遲拆解
scripts/test-openai.sh samples/sos.wav verbose_json   # OpenAI multipart 形狀
```

### endpoint 本身不是公開 REST API

SageMaker 的傳輸層強制 AWS SigV4 簽章，所以 endpoint **不能直接 curl**，也不能讓 HUB8735
直連（簽章鏈太重，且韌體不該持有 IAM 憑證）。要拿到真正可以 curl 的
`https://…/v1/audio/transcriptions`，前面得有一層「重新簽章、原封轉發」的代理。

三種做法，擇一：

| 做法 | 位置 | 適用 |
|---|---|---|
| **API Gateway + Lambda**（✅ 已部署） | `cloud/aws/lambda/asr-openai/` | AWS 平行環境；跟 `/voice`、`/tts` 同一個網域 |
| Render 語音 server 加路由 | `examples/asr-proxy-route.mjs` | 正式環境；零新增 AWS 資源 |
| 純 SDK 呼叫 | `examples/invoke.mjs` | 後端對後端，不需要 HTTP 門面 |

三者驗證方式一致：自訂金鑰走 `x-bf-vk` 或 `Authorization: Bearer`。

AWS 那條已經上線，部署與網址見
[`../aws/scripts/deploy-asr-openai.sh`](../aws/scripts/deploy-asr-openai.sh)：

```bash
bash cloud/aws/scripts/deploy-asr-openai.sh     # 冪等，重跑不會換掉既有金鑰
```

它掛的是既有的 `jinsun-voice-api`，開三條路由：`POST /v1/audio/transcriptions`、
`OPTIONS /v1/audio/transcriptions`、`GET /v1/models`。實測可直接餵給官方 OpenAI SDK：

```python
from openai import OpenAI
c = OpenAI(base_url="https://<api-id>.execute-api.us-west-2.amazonaws.com/v1", api_key="sk-jinsun-…")
c.audio.transcriptions.create(model="breeze-asr-26", file=open("samples/sos.wav", "rb")).text
# → '我跌倒了 站不起來 快來幫我'
```

⚠️ **音檔上限 4.5MB**（約 2 分鐘 16kHz mono）。這條路比 endpoint 本身的 6MB 更緊：
Lambda 同步呼叫的 payload 上限是 6MB，而 API Gateway 會把 binary body 做 base64（膨脹 4/3）。
⚠️ **單次請求上限 30 秒**（API Gateway HTTP API 的整合逾時硬上限，不可調）。

細節見 [`../../docs/requirements/asr-breeze-sagemaker.md`](../../docs/requirements/asr-breeze-sagemaker.md)。

## 目錄

| 路徑 | 說明 |
|---|---|
| `src/inference.py` | SageMaker handler：`model_fn` / `input_fn` / `predict_fn` / `output_fn` |
| `src/requirements.txt` | 容器啟動時安裝，版本與 DLC 的 cuDNN 綁定 |
| `scripts/` | fetch-model / deploy / redeploy / test / teardown / make-samples |
| `samples/` | 四段台灣國語長輩測試語音（跌倒求救／代購／沒事／領藥） |
| `model/` | 權重，gitignore，由 `fetch-model.sh` 重建 |

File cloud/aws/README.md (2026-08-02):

# AWS 平行環境

本目錄是**與現有 Render + Vercel + Supabase 環境功能等價、但完全跑在 AWS 上**的另一套部署。
兩套環境**互相獨立、不共用資料庫**；切換方式是改韌體的 `BASE_URL` 與 MQTT endpoint。

**接手請先讀 [`../../docs/requirements/aws-handoff.md`](../../docs/requirements/aws-handoff.md)**（環境識別碼、未完成項目、已知的坑、賽後清理）。

設計說明、實測數據與踩雷紀錄見 [`../../docs/requirements/aws-architecture.md`](../../docs/requirements/aws-architecture.md)。

## 為什麼要「不共用資料庫」

兩套環境若指向同一個 Supabase，會有三個問題：

1. **播報打架**——兩邊的進度 worker 都會反應同一筆 `dispatch_tasks` 變化，各自往自己的 broker 發，
   且各自維護去重狀態、互不知情。
2. **測試污染正式資料**——在 AWS 這側跑一次升級測試，就會在正式環境開出真的派遣單、推播到真實手機。
3. **不是真的「兩套環境」**——資料層是單點，任何一邊改壞 schema 兩邊一起死。

所以 AWS 這側要有自己的 **Aurora Serverless v2**（見下方待辦）。

## 目錄

```
cloud/aws/
├── lambda/
│   ├── voice/      POST /voice —— 沿用 cloud/prototype/src 的六個 agent，
│   │               只把 Emergency 的行程內 setTimeout 換成 Step Functions
│   ├── speak/      下發一句話到 IoT Core（Step Functions 的「說話」步驟）
│   ├── tts/        POST /tts —— 國語 TTS（Amazon Polly Zhiyu）。靠 Accept 分兩種回應：
│   │               韌體帶 audio/wav → WAV bytes；網頁版不帶 → {status,url}（data: URI）。
│   │               台語不走這裡：ATEN 那顆本來就是台語模型（且不吃 voice 參數），
│   │               裝置端依 speak 的 lang 分流。兩套環境共用（無狀態服務）
│   ├── progress/   進度播報 —— progress.js 的 AWS 版
│   ├── data/       三端 App 的資料 API（取代 Supabase PostgREST + Realtime）
│   │   ├── index.mjs   /data/version（變更指紋）、/data/snapshot、/data/mutate
│   │   ├── authz.mjs   角色授權 —— 取代 RLS 的那一層（純函式，有測試）
│   │   └── ops.mjs     具名寫入操作，可寫欄位寫死
│   ├── auth/       Cognito 觸發器：PreSignUp 自動確認、PostConfirmation 加 group＋寫 profiles
│   └── asr-openai/ POST /v1/audio/transcriptions —— SageMaker breeze-asr-26 的 OpenAI 相容門面。
│                   endpoint 本身已是 OpenAI 形狀（cloud/asr-sagemaker/src/inference.py），
│                   這支只做「驗金鑰 → 還原 base64 body → 換 octet-stream 轉發」，不解析 payload
├── stepfunctions/
│   ├── emergency-ladder.asl.json     20 秒逾時階梯（絕對時間戳）
│   └── enroute-broadcast.asl.json    路上每 10 分鐘（取代 setInterval）
├── iot/device-policy.json            裝置只能碰自己的 topic
└── scripts/
    ├── build.sh                      打包七支 Lambda
    ├── set-lambda-env.mjs            把 .env 裡的機密併進 Lambda 環境變數
    ├── setup-cognito.sh              User Pool + 三個 Group + App Client + 觸發器
    ├── deploy-data.sh                jinsun-data + API 路由 + JWT authorizer + 照片 bucket
    ├── deploy-tts.sh                 jinsun-tts + POST /tts 路由 + Polly 權限
    └── deploy-asr-openai.sh          jinsun-asr-openai + /v1/audio/transcriptions 路由
                                      （把 SageMaker breeze-asr-26 開成 OpenAI 相容 REST API）
```

**Lambda handler 不重複實作商業邏輯**——直接 import `cloud/prototype/src` 的
agents / dispatch / triggers / progress。`build.sh` 會在打包時把用到的模組複製進 bundle。
改播報文案或狀態機邏輯，只要改 `cloud/prototype/src` 一處，兩套環境同時生效。

## 打包與部署

```bash
bash cloud/aws/scripts/build.sh              # → cloud/aws/.build/*.zip
aws lambda update-function-code --function-name jinsun-voice \
  --zip-file fileb://cloud/aws/.build/voice.zip
```

機密（Supabase／Bedrock 金鑰等）不進版控，用腳本從 `cloud/prototype/.env` 併進去：

```bash
LAMBDA_FN=jinsun-voice node --env-file=cloud/prototype/.env \
  cloud/aws/scripts/set-lambda-env.mjs SUPABASE_URL SUPABASE_SECRET_KEY
```

## 已部署（us-west-2 / account 012804034919）

| 元件 | 資源 |
|---|---|
| `POST /voice` | API Gateway `jinsun-voice-api` → Lambda `jinsun-voice` |
| `POST /asr` | 同上（`$default` 路由）→ 代理 XCC Gateway 的 Breeze ASR，PAT 存 `XCC_GATEWAY_PAT` |
| 逾時階梯 | Step Functions `JinsunEmergencyLadder` + Lambda `jinsun-speak` |
| 進度播報 | Lambda `jinsun-progress` + Step Functions `JinsunEnrouteBroadcast` |
| 下行 MQTT | IoT Core（Thing `JS-0001`、`JS-REAL-0001`，policy `JinsunDevicePolicy`） |
| LLM | Bedrock（Sonnet 4.6 / Haiku 4.5） |
| 狀態 | DynamoDB `jinsun_emergency_sessions`、`jinsun_progress_announced` |
| **資料庫** | **Aurora Serverless v2 `jinsun-aurora`（PostgreSQL 16.14，Data API）** |

### 資料庫

```
cluster : jinsun-aurora        database: jinsun
engine  : aurora-postgresql 16.14（Serverless v2，0.5–4 ACU）
Data API: 已啟用 —— Lambda 不必進 VPC，也不必自己管連線池
密碼    : RDS 託管於 Secrets Manager（--manage-master-user-password），無人經手
```

> ⚠️ **最小容量刻意設 0.5 ACU 而非 0**。Serverless v2 從零擴容約需 15 秒，
> 那會直接吃掉 20 秒黃金窗——升級那一刻若資料庫正在冷啟動，派遣單會晚寫入。
> 每月約 $43 換取確定性，對這個系統值得。

Schema 由 `cloud/supabase/schema.sql` **自動轉換**產生，兩套環境共用同一份定義：

```bash
node cloud/aws/db/transform-schema.mjs > cloud/aws/db/schema.sql   # 產生（已 commit）
CLUSTER_ARN=... SECRET_ARN=... node cloud/aws/db/apply-schema.mjs  # 套用（--dry-run 可先看）
```

移除的四塊 Supabase 專屬語法：`auth.users` 外鍵、`fn_handle_new_user` 觸發器、
`supabase_realtime` publication、RLS policies。**資料表、型別、業務觸發器
（`fn_on_radio_event` / `fn_after_radio_event`）與種子資料完全保留**——
已驗證：22 位長輩、6 位志工、3 位社工、18 張證照、2 個業務觸發器都在。

## 待辦（達成「完全獨立」還缺的）

- [x] ~~Aurora Serverless v2~~ ✅ 已建並套用 schema + 種子資料
- [x] ~~Lambda 資料存取換成 Aurora Data API~~ ✅ **兩套環境已完全斷開**
      （`jinsun-voice` / `jinsun-progress` 的 `SUPABASE_*` 環境變數已移除，想碰也碰不到）
- [x] ~~`travel.js` 走 `db.js`~~ ✅ Aurora 沒有 Realtime → 改輪詢已接單的派遣單
- [x] ~~**Cognito**~~ ✅ User Pool `us-west-2_f34wIqjEd` + 三個 Group + `jinsun-auth` 觸發器已部署
- [x] ~~**三端資料層**~~ ✅ `jinsun-data`（REST + 變更指紋輪詢）已部署，四條路由掛 JWT authorizer。
      不用 AppSync 的理由見 [`aws-architecture.md` §4.4](../../docs/requirements/aws-architecture.md)
- [x] ~~`aws_backend.dart`~~ ✅ 已實作同一個 `BackendClient`；完整黃金鏈路已在真 AWS 上跑通
- [x] ~~三端 Flutter Web → S3 + CloudFront~~ ✅ 四端 HTTPS 站台已上線（含長輩端；網址見 handoff §0）
- [ ] `send-push` Edge Function → Lambda + SNS Mobile Push（`device_tokens` 已會寫進 Aurora）
- [x] ~~`whisper` Edge Function~~ ✅ 改成 `jinsun-voice` 的 `POST /asr` 代理，上游沿用同一個
      XCC Gateway（Breeze ASR）。刻意**不**用 Transcribe：Transcribe 沒有台語，換過去等於
      在台語長輩身上把辨識率換掉，而這條路徑正是長輩唯一的輸入方式
- [ ] 台語 ASR/TTS → SageMaker endpoint（Transcribe 無台語）

> 實測結果與踩雷紀錄見 [`aws-handoff.md` §3.2 / §6.7](../../docs/requirements/aws-handoff.md)。

## 三端 App 怎麼切到這一套

同一份 Flutter 原始碼，靠建置參數切換（見 `apps/packages/core/lib/src/backend_factory.dart`）：

```bash
export BACKEND=aws
export AWS_API_BASE=https://xxxx.execute-api.us-west-2.amazonaws.com
export COGNITO_CLIENT_ID=xxxx
bash deploy/aws/deploy-web.sh
```

App 內只有 `JinsunBackends` 這一個地方知道現在跑在哪一套；UI 一行都不用改。
參數缺一會退回 Supabase 並在 console 印警告——所以 `deploy-web.sh` 在 `BACKEND=aws`
時會**先檢查參數齊全才開始 build**，避免 build 出一個「看起來正常、資料卻連到正式環境」的站台。

## 資料層如何共用同一份程式碼

`cloud/prototype/src/db.js` 依 `DB_BACKEND` 回傳兩種 client：

| `DB_BACKEND` | 行為 |
|---|---|
| `supabase`（預設） | 直接回傳真正的 Supabase client —— Render 環境行為零改變 |
| `aurora` | 介面相容的薄殼，底層走 Aurora Data API |

**`dispatch.js` 等業務程式一行都沒改。** 兩套環境跑同一段查詢邏輯，才不會修好一邊、另一邊悄悄壞掉。

Data API 有兩個 PostgREST 會自動處理、它不處理的坑，`db.js` 已解決：

1. **enum 欄位**——Data API 參數一律是 `text`，Postgres 不會隱式轉成 `event_type_t`。
   轉接層查一次 `information_schema` 取得欄位型別並快取，每個參數自動加 `::型別`。
2. **`text[]` 陣列**——Postgres 陣列字面值是 `{"a","b"}` 而非 JSON `["a","b"]`。

> ✅ **已驗證斷開**：打一次 `/voice` 走完整升級鏈路後，
> Aurora `radio_events`/`dispatch_tasks` 各 +1，**Supabase 兩張表筆數完全未變**。

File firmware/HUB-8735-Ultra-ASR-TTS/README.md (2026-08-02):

# firmware（長輩端裝置）

收音機硬體端韌體。實測板為 **HUB8735 Ultra**（Realtek RTL8735B / AmebaPro2），語音互動 pipeline 已在此板實機跑通：**按鈕錄音 → 雲端 ASR → 雲端語音 Agent（`POST /voice`）→ 雲端 TTS → 喇叭播放**，並以 MQTT 常駐訂閱接收雲端下行指令。

程式碼：[`HUB-8735-Ultra-ASR-TTS.ino`](HUB-8735-Ultra-ASR-TTS.ino)

> 架構總覽與目標契約見 [`../docs/architecture.md`](../docs/architecture.md) 與
> [`../docs/requirements/hardware-integration.md`](../docs/requirements/hardware-integration.md)。
> 口袋型穿戴版（XIAO ESP32-S3）目前僅為設計概念，所有實測都在桌上型 HUB8735 Ultra 上進行。

## 已跑通的語音 pipeline（現況）

**上行（長輩主動觸發才錄音上雲）**

1. 長輩**按住按鈕 1 秒**（或**喊出聲**，見下方「本地聲音事件偵測」）→ 播 `init.wav` 提示音 → 開始錄音（板載 PDM 麥克風，16kHz mono，AAC/MP4 暫存 SD 卡；按鈕觸發最長 30 秒、**再按一下**或序列輸入 `stop` 提前結束，聲音喚醒則固定錄 8 秒後自動收工）
2. 錄音結束 → 播 `wait.wav` 墊住處理時間 → 音檔上傳**雲端 ASR**（faster-whisper Breeze-ASR-26，OpenAI 相容 `/v1/audio/transcriptions`）→ 取得中文文字
3. 文字送**雲端語音 Agent server**（`POST /voice`，帶 `device_serial`）→ 雲端做意圖分類、起 20 秒升級計時、必要時開派遣單，同步回一句要立刻播的 `reply`＋選用的 `action.command`
4. 回覆文字送**雲端 TTS**（回傳 WAV URL）→ 裝置以 HTTPS 串流邊下載邊播放（MAX98357 I2S 功放）

序列埠輸入 `sos` / `fall` 可模擬 SOS 鍵與相機跌倒事件（走同一條 `POST /voice`，`event` 欄位），沒有實體按鈕與相機時也能跑完整條鏈路。

## 本地聲音事件偵測（NPU / YAMNet）

板子的 NPU 從開機到關機一直在跑 YAMNet 音訊分類（521 類），**推論全程在裝置上、音訊從來不離開這塊板子**——
上行的只有「聽到什麼類別」導出的事件（`CLAUDE.md` 約束 1）。這補上了原本「長輩按不到按鈕就求救無門」的洞。

| 聽到 | 反應 |
|---|---|
| **求救聲**（Shout / Yell / Screaming / Crying / Whimper / Wail / Groan / Gasp，score ≥ 45） | 觸發**與長按按鈕完全相同**的喚醒錄音流程（錄 8 秒 → ASR → `POST /voice`），讓長輩把話講完再交給雲端分類 |
| **撞擊聲**（Thump / Bang / Slam / Smash / Breaking / Glass / Shatter…，score ≥ 60） | **只開一扇 3 秒「佐證窗」，絕不單獨上報** |
| **撞擊 → 3 秒內又聽到求救聲** | 兩個獨立訊號指向同一件事 → 直接送 `event:"fall_suspected"`，交給雲端 20 秒升級階梯（跳過問診：摔在地上的人可能已經講不出完整句子） |

設計上的幾個「為什麼」：

- **撞擊聲為什麼不能單獨上報**：關門、放鍋子、掉遙控器都會觸發，而每一次誤報都是一張真的志工派遣單。
  白名單也因此刻意排除 `Door` / `Knock` / `Dishes`——收進來的話佐證窗幾乎整天開著，等於沒有佐證。
- **喇叭出聲期間會關閉偵測**（`speakerOutputBegin/End`，停播後再多丟 1 秒）：麥克風聽得到自己的喇叭，
  不擋的話 TTS 的人聲會被判成 Shout → 「播報 → 誤判求救 → 又錄音 → 又播報」無限循環。
- **NN callback 只設旗標**（`onAudioClassified` 跑在 vipnn 執行緒），播音、開錄音、HTTPS 上報一律留到
  主迴圈的 `pumpSoundDetection()` 做——理由與 MQTT callback 那邊相同。
- **60 秒喚醒冷卻**：一次喚醒後面接的是錄音→ASR→/voice，幾十秒跑不完；沒有冷卻的話電視劇裡一段爭吵
  就能連開十幾張單。
- 門檻（`distressScoreThreshold` / `impactScoreThreshold`）與白名單都寫在 .ino 開頭，**預期要在場域實測後調**。
  每一筆進了白名單的偵測都會印 `[SND] …` log 帶類別名與分數，就是拿來調這兩個數字的。

不用真的摔東西也能驗判斷邏輯——序列埠輸入：

| 指令 | 作用 |
|---|---|
| `shout` | 偽造一筆求救聲偵測 |
| `bang` | 偽造一筆撞擊聲偵測（開佐證窗） |
| `sndreset` | 清除冷卻與佐證窗 |
| `snddebug` | 切換診斷模式：**每一次**推論都印出前 3 名（不管有沒有進白名單、有沒有過門檻） |

`bang` 後 3 秒內打 `shout` → 應該看到 `fall_suspected` 上報；單獨打 `shout` → 應該進喚醒錄音。

`snddebug` 是調門檻與確認模型活著的主要工具——平常的 `[SND]` log 本身就被門檻擋著，
「喊了沒反應」到底是模型沒載進去、麥克風沒收到聲音、還是分數差一點，只有這個模式分得出來：

```
[SND] (raw)  Silence(494)=87  Speech(0)=6  Inside, small room(506)=3
[SND] (raw)  Shout(6)=41  Speech(0)=33  Yell(9)=12     ← 41 差一點沒過 45，門檻要往下調
```

> ⚠️ **編譯設定**：Arduino IDE 的 **Tools → NN Model Load From 要維持 `Flash`**（預設值）。
> 選 SD Card 的話要自己把模型檔放進記憶卡根目錄，而這張卡同時在存錄音，不值得多這個變數。
>
> ⚠️ **YAMNet 不是關鍵字辨識器**：它分得出「有人在大聲喊」，分不出喊的是「救命」還是「小金孫」。
> 離線喚醒詞／急救詞仍是待辦，要另外訓練 KWS 模型。
>
> 整段功能可用 .ino 開頭的 `#define ENABLE_SOUND_DETECTION 0` 關掉，退回純按鈕觸發。

**下行（雲端主動找長輩說話）**

開機後以 MQTT 常駐訂閱 `jinsun/{serial}/cmd`（QoS 1），雲端的急救逾時階梯與志工進度播報就靠這條推過來：收到 `{"commands":[…]}` 後 `speak` 送 TTS 發聲、`device` 執行 `volume_up`／`volume_down`／`repeat`／`stop_speak`。連線設 Last Will（`jinsun/{serial}/status` = `offline`），後台的「裝置離線」顯示不需另做心跳。斷線以指數退避重連（1s→2s→…→30s），重連後重新訂閱並補發 `online`。

> 指令在 MQTT callback 裡只入佇列、回主迴圈才播——callback 內直接播 TTS 會卡住收訊迴圈導致 keep-alive 斷線，而 QoS 1 重連後 broker 會重送同一則，變成無限循環播報。

開機自檢：WiFi 連上後，SD 卡正常播 `ready.wav`（無檔案則合成上揚雙音）；SD 卡異常合成三聲低音警告。

## 硬體接線（HUB8735 Ultra）

| 元件 | 接法 |
|---|---|
| 觸發按鈕 | D9 ↔ GND（`INPUT_PULLUP`，按下 = LOW；D12 被 I2S 佔用、D13 是閃光燈 PWM，不可用） |
| MAX98357 I2S 功放 | BCLK→D24、LRC→D12、DIN→D11、SD_MODE→D10（同時佔用 D22/D23，板載按鈕不可用） |
| 麥克風 | 板載數位 PDM，`AudioSetting(3)`＝16kHz Mono Digital PDM（設成類比會錄到一片死寂，實測 -74dBFS）。同一份輸入以 SIMO StreamIO 分流給 AAC 錄音與 NPU 音訊分類——YAMNet 也只吃 16kHz，設定完全共用，不必開第二條音訊管線 |
| SD 卡 | 錄音暫存 `test.mp4`；提示音 `ready.wav` / `init.wav` / `wait.wav` |

## 外部服務（常數寫在 .ino 開頭，可抽換）

**兩套雲端環境**共存，靠 .ino 開頭的 `#define BACKEND_AWS`（`0`／`1`）切換，**契約完全相同**——
topic、payload、QoS、LWT、`/voice` 的請求與回應逐欄位一致，差別只有端點與憑證：

| 用途 | `BACKEND_AWS 0`（正式環境） | `BACKEND_AWS 1`（AWS 平行環境） |
|---|---|---|
| 語音 Agent（大腦） | `jinsun-voice-server-mg1f.onrender.com/voice`（Render + Supabase） | `yr0ep335el.execute-api.us-west-2.amazonaws.com/voice`（API Gateway → `jinsun-voice` Lambda + Aurora） |
| MQTT broker（下行） | `mqttgo.io:8883`（TLS，公共 broker、無認證；鏈根 ISRG Root X1） | `a2zyk2buv4tih2-ats.iot.us-west-2.amazonaws.com:8883`（AWS IoT Core，**X.509 雙向 TLS**；鏈根 Amazon Root CA 1） |
| 上行逾時 | 60 秒（Render 免費方案冷啟動 30–60 秒） | 30 秒（API Gateway 整合逾時上限） |

⚠️ **兩套環境不共用資料庫**：切到 AWS 之後，這台的事件只會出現在 AWS 那三端網址上，正式環境的家屬 App 看不到（反之亦然）。開機第一行 `[ENV] …` log 就是在講現在連的是哪一套。詳見 [`../docs/requirements/aws-handoff.md`](../docs/requirements/aws-handoff.md)。

兩套環境共用的部分（不隨開關改變）：

| 用途 | 服務 |
|---|---|
| ASR | `…execute-api.us-west-2.amazonaws.com` `/v1/audio/transcriptions`，model `breeze-asr-26` —— 自家的 SageMaker endpoint（faster-whisper Breeze-ASR-26 fp16），由 `jinsun-asr-openai` Lambda 開成 OpenAI 相容介面。部署：`bash cloud/aws/scripts/deploy-asr-openai.sh`。兩套環境共用（無狀態服務，同國語 TTS）。金鑰是 `sk-jinsun-…`，走 `x-bf-vk` 標頭（那支 Lambda 也吃 `Authorization: Bearer`）。**舊的 `llm-gateway.xcc.tw` 保留在 .ino 的註解裡當備援**——SageMaker 是 GPU 機型、會被 teardown 收掉，收掉時取消註解那四行即可切回 |
| TTS（`lang=taigi`） | `kws.oaselab.org` `/nutntweng/tts/aten/` —— **ATEN 台語模型**（回 JSON 帶 WAV URL，再 GET 串流播放）。端點不吃 voice/lang 參數，只會講台語 |
| TTS（`lang=mandarin`） | `…execute-api.us-west-2.amazonaws.com` `/tts` —— **Amazon Polly Zhiyu**（`jinsun-tts` Lambda）。韌體帶 `Accept: audio/wav`，回應本身就是 WAV，POST 完直接串流播放（實機驗過）。部署：`bash cloud/aws/scripts/deploy-tts.sh`。兩套環境共用（無狀態服務，同 ASR gateway）。**音量在雲端正規化**（Polly 原始輸出峰值只到 −10 dBFS，聽起來偏小聲；Lambda 拉到 −1 dBFS，+9 dB）——不要改用 `ampVolume` 補，那會連台語一起變大聲 |

原本的「直連 Google Gemini」已移除——直連 LLM 時雲端不知道有人在求救，長輩的話進不了急救狀態機。

### 走 AWS 要先燒憑證

AWS IoT Core 用 X.509 認裝置身分，**沒有憑證就完全收不到下行指令**（急救逾時階梯的三句話都不會播）。
私鑰無法從 AWS 取回，遺失就重簽一組：

```bash
THING=JS-0001                    # 必須與 .ino 的 device_serial 完全相同
aws iot create-keys-and-certificate --set-as-active \
  --certificate-pem-outfile device.cert.pem \
  --private-key-outfile device.key.pem \
  --public-key-outfile device.public.pem \
  --query certificateArn --output text > cert.arn
aws iot attach-policy --policy-name JinsunDevicePolicy --target "$(cat cert.arn)"
aws iot attach-thing-principal --thing-name "$THING" --principal "$(cat cert.arn)"
```

把兩個 PEM 的內容貼進 `secrets.h`（複製 [`secrets.h.example`](secrets.h.example)，已在 `.gitignore`）。
沒填憑證時韌體**不會靜默重試**，開機會直接印出缺憑證的原因——因為 AWS IoT 對認證／授權失敗是
直接切斷 TCP、不回錯誤碼，症狀長得跟「網路不穩」一模一樣，不講清楚會查錯方向。

### MQTT 一直重連（連上約 0.5 秒就斷）

```
[MQTT] 已連線,訂閱 jinsun/JS-0001/cmd (QoS 1)
[MQTT] ✗ 斷線（這次連線撐了 535 ms）state=-3 errno=128
[MQTT] 連線中 …                                    ← 無限循環
```

**先讀那兩個數字，它們直接決定往哪查**（2026-08-01 實測到的就是下表第一列）：

| 症狀 | 意思 | 往哪查 |
|---|---|---|
| `state=-3` `errno=128` | `errno 128` = **ENOTCONN**（newlib 編號，見 toolchain 的 `sys/errno.h`；不是 lwIP 的 107）＝**對端主動關閉連線**。TLS 握手與 CONNECT 都過了才被踢 | **雲端授權**，見下方 |
| `state=-4` | keep-alive ping 沒等到回應 | 網路／broker 可達性，不是授權 |
| 連 `已連線` 都印不出來、`rc=-2` | TLS 握手就失敗 | 憑證內容、系統時鐘（`tv.tv_sec`） |

**「接受 CONNECT、半秒後斷線」是 AWS IoT 對授權失敗的標準反應**——它不回錯誤碼，直接斷 TCP。
`iot:Connect` 在 CONNECT 當下就判過了，subscribe／publish 是之後才被拒，那個時間差就是那半秒。

#### 已知成因：`setPublishQos(1)` 其實打開的是 RETAIN 旗標（2026-08-01 查明，已修）

這個坑值得完整寫下來，因為每一條線索都指向錯的方向：Thing、憑證、policy 三者查起來全都正確
（`list-thing-principals`／`list-attached-policies`／`get-policy-version` 都對得上），憑證也 ACTIVE、
時鐘也在 `notBefore` 之後，TLS 握手更是明明過了。

真正的原因在韌體這行（原本寫在 `setup()`）：

```cpp
mqtt.setPublishQos(1);    // 想讓上下線狀態走 QoS 1
```

SDK 的這支 API 收的是**已經位移過的常數**——`#define MQTTQOS1 (1 << 1)`，值是 **2 不是 1**。
而實作是 `header |= pub_qos;`，MQTT 固定標頭的位元配置是：

```
[type:4][DUP:1][QoS:2][RETAIN:1]        ← bit 0 是 RETAIN
```

所以傳 `1` 進去不是設 QoS 1，是**把 RETAIN 打開**。`publish("jinsun/{serial}/status","online")`
就變成一則保留訊息，而 **AWS IoT 對保留訊息要求另一個權限 `iot:RetainPublish`**，
[`device-policy.json`](../../cloud/aws/iot/device-policy.json) 只給了 `iot:Publish` → 被拒 → 關閉連線。

> 那改成 `setPublishQos(MQTTQOS1)` 不就好了？**不行**。SDK 的 QoS≥1 分支還有第二個 bug：
> ```cpp
> buffer[id_pos]   = (nextMsgId >> 8);
> buffer[id_pos++] = (nextMsgId & 0xFF);   // 後置遞增 → 兩行寫到同一格
> ```
> MSB 被 LSB 蓋掉，第二個位元組從沒被寫入（留著上一個封包的殘值），送出去的 packet identifier 是壞的。

**現在的作法是不呼叫 `setPublishQos()`，status 用預設 QoS 0。** 這不影響可靠性：status 只是「我在線」的
標記，離線那半由 LWT 負責；真正需要保證投遞的下行指令走的是 **subscribe QoS 1 + `cleanSession=false`**，
與 `setPublishQos` 無關。（若哪天真的想要 retained status，得同時在 policy 加 `iot:RetainPublish`
並把 LWT 也改成 `willRetain=true`，否則上線保留、離線不保留，後台看到的狀態會是錯的。）

#### 其它可能

- 憑證沒 attach 到 Thing → policy 的 `${iot:Connection.Thing.ThingName}` 解不出值 → 全被拒：
  ```bash
  aws iot list-thing-principals --thing-name JS-0001 --region us-west-2   # 空陣列就是這個原因
  aws iot attach-thing-principal --thing-name JS-0001 --principal "<certArn>" --region us-west-2
  ```
- 另一個 client 用同一個 client id 連線 → IoT Core 踢掉舊的那條，兩邊互踢。
  ⚠️ policy 把 client id 綁死成 Thing 名稱，所以**電腦上的 `mosquitto_sub` 只能用 `-i JS-0001`，
  必然跟裝置互踢**——要旁聽下行請先把裝置斷電，不能同時連。

**不用 AWS 帳號也能先分流**：把 `.ino` 的 `BACKEND_AWS` 改成 `0` 燒一次，那條走 mqttgo.io（公共 broker、
無認證，也不在意 retain）。MQTT 穩了 → 確定是 AWS 授權那側；一樣每 0.5 秒斷 → 成因在更底層。

> 斷線期間**聲音偵測與上行 `POST /voice` 都不受影響**（走序列埠與 HTTPS，不經 MQTT），
> 只有「雲端主動下發 `speak`」那條下行鏈路會斷。

## 已知限制／注意事項

- WiFi SSID/密碼、ASR API key、AWS IoT 裝置憑證與私鑰都走 `secrets.h`（未追蹤，範本
  [`secrets.h.example`](secrets.h.example)）。.ino 只留佔位符，沒有 `secrets.h` 也編得過但連不上。
  長期目標仍是 BLE 配網＋安全儲存（Flash 加密分割區）
- 開機以 `settimeofday` 強制設定系統時間來通過 SSL 憑證驗證（板子無 RTC/NTP）。
  ⚠️ **重燒韌體時必須把 `tv.tv_sec` 更新到接近當天**（`date +%s`）：mqttgo.io 用 Let's Encrypt
  的 90 天短效憑證，時間設得太早會被判「憑證尚未生效」而連不上 MQTT。走 AWS 時根憑證雖然到 2038，
  但**裝置憑證是重簽當天才生效**，一樣會被時鐘卡住
- `lang` 分流已實作：`taigi` → ATEN（台語模型）、`mandarin` → Polly Zhiyu。雲端不做台語翻譯
  （`text` 一律正常中文，`lang` 只是選語音的旗標）。Polly 那條路失敗時**退回 ATEN**，長輩會聽到
  台語版的同一句——寧可語言不對也不要安靜，序列埠會印 `[TTS] ⚠️ 國語 TTS 不可用 → 退回 ATEN`。
  ✅ **台語餵國語書寫已實聽確認可行**（台文寫法雖然不同，例：「雞蛋」→「雞卵」，但 ATEN 念得出來），
  所以雲端不必為 `lang` 產兩份文字
- `stop_speak` 只能清空待播佇列，無法中斷正在播放的那一句（`playWavStream` 是阻塞的）
- MQTT 連線在長時間阻塞操作（ASR 上傳、TTS 播放）期間可能逾時斷線，**這是刻意接受的**：
  在 ASR 等待迴圈裡呼叫 `mqttPump()` 會讓 TLS 握手阻塞數秒、誤判「安靜夠久＝收完了」而截斷回應。
  改靠 `cleanSession=false` ＋ QoS 1，斷線期間的指令由 broker 在重連後補投
- ⚠️ **flash 只剩約 16%**：加上音訊分類後從 28% 跳到 84%（`yamnet_fp16.nb` 一個模型就 8.7 MB）。
  之後要加 YOLO 跌倒偵測（`yolov4_tiny.nb` 4.1 MB／`yolov7_tiny.nb` 4.7 MB）**幾乎確定塞不下**。
  逃生口是 `variants/common_nn_models/yamnet_s_hybrid.nb`（只有 320 KB，SDK 內部符號 `yamnet_s`），
  但 `NNAudioClassification::begin()` 把 `&yamnet`（fp16）寫死了，要用小模型得繞過包裝層直接呼叫
  `vipnn_control(CMD_VIPNN_SET_MODEL, &yamnet_s)`——**尚未驗證**
- 聲音偵測**沒有「模型載入失敗就退回音量門檻」的降級路徑**：`NNAudioClassification::begin()` 回傳 void，
  SDK 也沒有查詢載入結果的 API。目前只能靠編譯期的 `ENABLE_SOUND_DETECTION` 開關切回純按鈕模式，
  開機的 `[SND] 喚醒模式：…` log 是現場唯一能確認偵測有沒有開的依據
- `NNAudioClassification.h` 為了引入 `<vector>` 會 `#undef min` / `#undef max`，**Arduino 的 min()/max()
  巨集在這個 .ino 裡已經不存在**（音量夾值改用自寫的 `clampVolume()`）。之後在本檔案新增程式碼時要注意
- 尚未實作：跌倒偵測相機（Himax WiseEye2）、「小金孫」喚醒詞與離線急救詞「救命」、BLE 配網

## 編譯檢查（不用開 IDE）

Arduino IDE 2.x 內建了 arduino-cli，可以直接拿來驗證編譯：

```bash
CLI="/Applications/Arduino IDE.app/Contents/Resources/app/lib/backend/resources/arduino-cli"
"$CLI" compile --fqbn ideasHatch:AmebaPro2:Ameba_HUB-8735_ultra firmware/HUB-8735-Ultra-ASR-TTS
```

## 對測（不用實機）

`device_serial` 硬編碼在 .ino 開頭，預設 `JS-0001`。用 mosquitto 當假裝置即可驗下行：

```bash
# 正式環境（BACKEND_AWS 0）
mosquitto_sub -h mqttgo.io -t 'jinsun/JS-0001/cmd' -v     # 收雲端 push
curl -s https://jinsun-voice-server-mg1f.onrender.com/voice \
  -H 'content-type: application/json' \
  -d '{"device_serial":"JS-0001","text":"我跌倒了"}'      # 觸發問診→逾時階梯
```

AWS 環境（`BACKEND_AWS 1`）同一組驗證——下行要帶憑證才訂閱得到：

```bash
API=https://yr0ep335el.execute-api.us-west-2.amazonaws.com
curl -s $API/health                                        # {"ok":true,...,"ladder":true}
curl -s $API/voice -H 'content-type: application/json' \
  -d '{"device_serial":"JS-0001","text":"我跌倒了"}'

mosquitto_sub -h a2zyk2buv4tih2-ats.iot.us-west-2.amazonaws.com -p 8883 \
  --cafile AmazonRootCA1.pem --cert device.cert.pem --key device.key.pem \
  -i JS-0001 -t 'jinsun/JS-0001/cmd' -v
```

> `-i JS-0001` 不能省：IoT Policy 用 `${iot:Connection.Thing.ThingName}` 限縮 client id，
> 名字對不上會被**直接斷線**（不是回錯誤碼）。

完整契約與交接清單見 [`../docs/requirements/hardware-integration.md`](../docs/requirements/hardware-integration.md)。

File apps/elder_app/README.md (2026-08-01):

# elder_app — 長輩端收音機（網頁版）

實體收音機的網頁替身：一顆佔滿下半螢幕的「按住說話」大按鈕、一張大字卡片，
沒有選單、沒有設定頁、沒有登入畫面（架構約束 2：長輩端沒有 UI）。
給沒有硬體在手上時做 demo 與對測用；真機的行為契約見
[`docs/requirements/hardware-integration.md`](../../docs/requirements/hardware-integration.md)。

一次互動的流程：

```
按住大按鈕錄音（WAV 16k 單聲道）
  → 放開 → BackendClient.transcribeAudio() 拿逐字稿
  → POST /voice（多 Agent 決定求助／代辦／閒聊）
  → 念出回覆（雲端 TTS，打不通退回瀏覽器語音）
```

另外會即時播報進行中的派遣：志工接單念「正在過來，大約 N 分鐘到」、到場念「到您家門口了」。

## 啟動

```bash
flutter pub get
flutter run -d chrome        # 麥克風要 HTTPS 或 localhost，其他網域拿不到權限
```

網址參數：`?elder=elder-1` 或 `?serial=JS-0001` 指定這台是誰的收音機；都沒帶就用清單第一位。

## 兩套環境

後端由 `--dart-define=BACKEND` 決定，切換點只有 `apps/packages/core` 的 `backend_factory.dart`
（見 [`docs/requirements/aws-handoff.md`](../../docs/requirements/aws-handoff.md)）。

| | Supabase（正式） | AWS（平行環境） |
|---|---|---|
| 資料層 | Supabase Realtime | API Gateway `/data/*`（3 秒輪詢） |
| 登入 | 不需要 | **需要**——Cognito 裝置帳號，開機自動登入 |
| ASR | `whisper` Edge Function | `POST /asr`（`jinsun-voice` Lambda 代理） |
| TTS | `/tts` 代理 ATEN | 未接，自動退回瀏覽器語音 |

AWS 版要多帶裝置帳密（長輩不可能自己登入，所以在 build 時注入）：

```bash
flutter build web --release \
  --dart-define=BACKEND=aws \
  --dart-define=AWS_API_BASE=https://xxxx.execute-api.us-west-2.amazonaws.com \
  --dart-define=COGNITO_CLIENT_ID=xxxx \
  --dart-define=ELDER_DEVICE_USER=device-js-0001@jinsun.local \
  --dart-define=ELDER_DEVICE_PASS=...
```

平常不用手打，`bash deploy/aws/deploy-web.sh` 會帶好（AWS 站台）、
`bash deploy/deploy-all.sh` 會部署 Vercel 那套。

一個裝置帳號只綁一位長輩，所以這台在後端只看得到那一位——一台收音機就是一位長輩的，
看得到別人是授權破口。要再開一台就另建帳號並重 build 一份站台。

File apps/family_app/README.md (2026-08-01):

# family_app（家屬 App）

給家屬掌握長輩即時狀態的手機 App。

- **平台**：Flutter（Android／iOS）
- **角色**：家屬
- **功能**：安心日報／週報、緊急通知推播、事件與派遣進度即時更新

詳見 [`../../docs/architecture.md`](../../docs/architecture.md) 與 [`../../docs/requirements/phase1-mvp.md`](../../docs/requirements/phase1-mvp.md)。

## 啟動方式

```bash
flutter pub get
flutter run -d chrome    # 或 -d macos / 手機模擬器
flutter test
```

## 狀態

Phase 1 薄閉環：長輩狀態卡、通知 feed、派遣進度（虛擬志工自動接單）、demo 面板（模擬疑似跌倒／SOS／回應沒事）。資料層為 `jinsun_core` 的 `MockBackend`，無真後端。

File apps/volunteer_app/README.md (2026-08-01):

# volunteer_app（志工 App）

給志工接單、確認長輩需求與到場回報的手機 App。

- **平台**：Flutter（Android／iOS）
- **角色**：志工
- **功能**：查看長輩物資需求並接單採買、緊急派遣單接單、到場回報「已安全」、時間銀行點數

詳見 [`../../docs/architecture.md`](../../docs/architecture.md) 與 [`../../docs/requirements/phase1-mvp.md`](../../docs/requirements/phase1-mvp.md)。

## 啟動方式

```bash
flutter pub get
flutter run -d chrome    # 或 -d macos / 手機模擬器
flutter test
```

## 狀態

Phase 1 薄閉環：任務列表（緊急派遣／物資代購）、接單填 ETA → 到場 → 回報流程、時間銀行點數、demo 面板。資料層為 `jinsun_core` 的 `MockBackend`，無真後端。

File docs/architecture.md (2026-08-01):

# 系統架構

## 1. 整體架構

家中近端（國產晶片・預設不上雲）→ AWS 雲端（事件觸發才上雲）→ 使用者端（家屬 App／志工 App／社工 Web 後台）。

系統架構圖

### 家中近端（全國產晶片・預設不上雲）

> ⚠️ **硬體型態尚未定案**，目前有兩版設計圖並存：
> 1. 上圖：**桌上型收音機**，主控為 Realtek AmebaPro2——**實測韌體已在此版跑通**（HUB8735 Ultra，`firmware/HUB-8735-Ultra-ASR-TTS.ino`：按鈕錄音 → 雲端 ASR → LLM → 雲端 TTS 播放，見 `firmware/README.md`）
> 2. 下圖：**口袋型穿戴式**（掛脖／別胸口／背包夾），主控為 XIAO ESP32-S3，跌倒視覺辨識同樣用 Himax WiseEye2（透過 Grove Vision AI V2 模組）
>
> 口袋型穿戴式產品外觀與零件圖
>
> 口袋型版本硬體規格：55×38×18mm（不含吊繩）、約 68g、18650 鋰電池 3.7V 2000mAh（USB-C 充電）、續航約 3–5 天、喇叭輸出 2W、感測為 AI 視覺辨識＋3 軸加速度計＋麥克風陣列。主要模組：LED 狀態燈條、隱藏式攝影機模組（Himax WiseEye2）、麥克風陣列、Grove Vision AI V2、MAX98357A 數位功放、內建喇叭、XIAO ESP32-S3 控制板、SOS 大按鍵模組、可折疊立式支架、背夾結構。
>
> 兩版本在「感知＋決策＋行動」的軟體邏輯上是一致的（見下方），差異只在主控晶片與外型。**目前所有實測都在桌上型（HUB8735 Ultra）上進行**，口袋型僅為設計概念；待定案後，本文件與 `firmware/README.md` 統一改寫，移除另一版描述。

| 元件 | 角色 |
|---|---|
| Himax WiseEye2（奇景光電） | 跌倒視覺推論；影像不外傳，僅本地端運算 |
| Realtek RTL8735B / AmebaPro2（實測板：**HUB8735 Ultra**） | 主控、麥克風收音、Wi-Fi、**BLE 5.1**（家屬 App 藍牙配網）、TTS 發聲 |

> 裝置↔雲端對接（藍牙配網＋上行 `POST /voice`＋下行 MQTT push：裝置訂閱 `jinsun/{serial}/cmd`，server publish 觸發 TTS 發聲；原型 broker 為 server 內嵌 aedes、正式為 AWS IoT Core）見
> [`requirements/hardware-integration.md`](requirements/hardware-integration.md)。RTL8735B 內建 BLE 5.1，
> Ameba Arduino SDK 有現成 `BLEWifiConfig` 服務可供家屬 App 對接。

長輩不需要學習操作任何 App，收音機本身就是完整的互動介面：

- **相機＋ML model**：偵測跌倒／久臥等異常姿態，模型跑在裝置端，畫面不外傳（規劃中，尚未實作）
- **麥克風**：**本地 NPU 音訊分類（YAMNet，已實作）**——聽到呼救／尖叫／呻吟（distress 類）即自動開始錄音，長輩喊得出聲但按不到按鈕時也能求救；聽到撞擊／摔落聲則開一扇 3 秒「佐證窗」，**撞擊聲絕不單獨上報**（關門、放鍋子都會觸發，每次誤報都是一張志工派遣單），窗內若再聽到呼救才判定疑似跌倒。推論全程在裝置 NPU 上跑，**音訊不外傳**。「小金孫」喚醒詞與異常沉默偵測仍規劃中；實體按鈕是不依賴任何模型的最終退路
- **語音播報（TTS）**：詢問「你有沒有撞到？」、告知「已經幫你叫人，預計 6 分鐘內到」等安撫與狀態回報
- **SOS 實體按鈕**：一按直接觸發求助流程
- **主動代辦語音**：長輩可直接跟收音機說想要的物資（如「我想買牛奶跟雞蛋」），這段語音才會上傳雲端；其餘時間（吃藥提醒、日常監測）都在本地端處理，長輩不會覺得被監視

隱私設計的關鍵邊界：**影像永不外傳**（跌倒推論在裝置本地完成），語音只有長輩**主動觸發**的段落會上雲做 ASR（對應架構約束 1）。聲音事件喚醒不打破這條線——YAMNet 分類在裝置 NPU 上完成，上行的只有「聽到什麼類別」導出的事件；被判定為求救而錄下的那一段，與按鈕觸發走完全相同的路徑。裝置↔雲端只送事件與文字：上行走 HTTPS `POST /voice`，下行**定案走 MQTT push**。實測韌體（`firmware/HUB-8735-Ultra-ASR-TTS.ino`）**上下行都已接上契約**：上行打部署於 Render 的語音 Agent server（`https://jinsun-voice-server-mg1f.onrender.com/voice`），下行以 PubSubClient 訂閱 `jinsun/{serial}/cmd`（QoS 1、LWT 上下線、指數退避重連）。broker 佈署有三種型態：本機開發＝server 內嵌 aedes；**Render 部署＝server 與裝置各自連同一顆外部 broker 會合**（server 設 `MQTT_URL`，因 PaaS 只對外開 HTTPS、內嵌 broker 進不來）；正式＝AWS IoT Core（換 endpoint＋憑證，topic 與 payload 不變）。

### AWS 雲端

> 📐 **完整 AWS 目標架構、服務對應、部署方式與分階段落地計畫**（含 Bedrock / SageMaker AI / Kiro 的具體用途、成本估算、IoT Policy 與 Step Functions 骨架）見
> [`requirements/aws-architecture.md`](requirements/aws-architecture.md)。下表為摘要。
>
> 🟢 **想看「現在實際跑著什麼」**（每個資源都用 `aws` CLI 查證過、哪些線是通的、哪些還沒接）見
> [`requirements/aws-architecture.md` §2.1 現況架構總圖](requirements/aws-architecture.md#21-現況架構總圖2026-08-01-實查)。
> 下表與 §2 目標圖都含尚未建置的服務，**不要當成現況讀**。

括號標註為目前規劃中、尚未實作的原型程式對應（Node.js）：

| AWS 服務 | 用途 | 原型對應 |
|---|---|---|
| AWS IoT Core | 下行指令 push（裝置訂閱 `jinsun/{serial}/cmd`）、接收裝置 MQTT 事件 | aedes MQTT broker（已內嵌於 `cloud/prototype`，見 `src/mqtt.js`） |
| API Gateway + Lambda | 語音文字入口 `POST /voice` | `cloud/prototype/`（已建） |
| LLM（意圖分類／需求解析／陪伴對話） | 語音多 Agent server 的大腦 | `cloud/prototype/`（已建）。**預設走 API key 的 OpenAI 相容閘道**（XCC Gateway，與 ASR 同一把金鑰）；可選 AWS Bedrock 或 mock。供應商由**社工後台即時切換**（Supabase `app_settings.llm_provider`，server 短快取讀取，免重新部署） |
| Step Functions + Lambda | 事件分級、20 秒升級判斷、派遣狀態機 | Emergency Agent 逾時階梯 + 既有 Supabase 狀態機 |
| Aurora Serverless v2（Data API） | 三端與派遣的關聯式資料 | Supabase Postgres（現行）。轉接層 `cloud/prototype/src/db.js` 讓兩套環境跑同一段查詢 |
| API Gateway + `jinsun-data` Lambda | 三端 App 的資料讀寫（取代 PostgREST + Realtime） | Supabase client + Realtime 訂閱。AWS 側改用「變更指紋輪詢」，理由見 [`requirements/aws-architecture.md`](requirements/aws-architecture.md) §4.4 |
| Cognito User Pool（3 個 Group） | 家屬／志工／社工的身分與角色 | Supabase Auth + RLS。RLS 的等價規則重寫在 `cloud/aws/lambda/data/authz.mjs` |
| DynamoDB | Emergency session、長期記憶等 key-value 狀態 | 記憶體 Map + Memory Agent |
| Transcribe（或 OpenAI Whisper） | **家屬↔志工聊天的語音輸入轉文字**（ASR） | Supabase Edge Function `whisper`（已建，`cloud/supabase/functions/whisper`） |
| Amazon SNS Mobile Push / Pinpoint | **背景推播**（App 關閉／在背景時的系統通知） | FCM + APNs（已建）＋ Supabase Database Webhook → Edge Function `send-push`（已建，`cloud/supabase/functions/send-push`） |

**語音多 Agent server（`cloud/prototype/`，設計文件 [`requirements/voice-agent-server.md`](requirements/voice-agent-server.md)，A2A 架構圖／flow／sequence 見 [`requirements/voice-agent-a2a-flow.md`](requirements/voice-agent-a2a-flow.md)）**
是長輩「主動語音互動」的雲端大腦：硬體負責觸發＋收音＋發聲（錄音經雲端 ASR 轉成文字、回覆經雲端 TTS 發聲），文字進 server 後由 Intent / Emergency /
Needs / Conversation / Device / Memory 六個 Agent 分工——閒聊就地回覆，緊急與需求則寫進
`radio_events` / `dispatch_tasks`，接上既有派遣鏈路觸發三端推播。

server 另有一個**進度播報 worker**（`src/progress.js`）：訂閱 Supabase `dispatch_tasks` 的
Realtime 狀態變化，志工「接單(accepted)」「抵達(arrived)」時，反查長輩 `device_serial` 與
`preferred_lang`，透過下行通道主動下發 `speak`（帶 `lang`）→ 收音機念出「志工○○大約○分鐘到，您再等一下喔」。
這補上了「感知→決策→行動→回報」閉環裡長輩端唯一的主動出口。**播報語言（國語／台語）**由家屬在 App
設定（`elders.preferred_lang`），裝置端 TTS 依 `lang` 分流到兩顆服務——`taigi` → ATEN（台語模型）、
`mandarin` → Amazon Polly Zhiyu（`jinsun-tts` Lambda）；ATEN 端點不吃 voice 參數、只會講台語，
所以國語必須是另一顆（正式對應：DynamoDB Streams → Lambda → IoT Core）。

同一個 worker 另訂閱 `volunteers` 的座標變化（志工 App `LocationPublisher` 上報的真實 GPS，
demo 則由 `travel.js` 模擬）：志工走進長輩家 **250 公尺**（`APPROACH_METERS`）內，就先播一句
**「志工○○快到您家門口了，等一下會敲門，是我們派來幫您的」**。理由是長輩獨居、突然被敲門會怕，
`arrived` 那句「到您家門口了，馬上進來看您」是人已在門口才念，對行動慢的長輩太晚。同一張單只預告一次；
若志工一上報就已在到場門檻（60m，與 `isNearbyMeters` 一致）內，則跳過預告、只留「到囉」那句，
避免兩句連珠炮。距離判定在雲端算，志工 App 不必改動上報邏輯。

> **ASR / TTS 位置（依實測韌體修正：都走雲端服務）**。實測韌體（`firmware/HUB-8735-Ultra-ASR-TTS.ino`）
> 由長輩按鈕主動觸發錄音，把**該段音檔**上傳雲端 ASR（faster-whisper Breeze-ASR）轉成文字；TTS 也由
> 雲端服務合成音檔、裝置串流播放。隱私邊界回到約束 1 的原始定義：**只有主動觸發的語音段落上雲，
> 影像永不外傳**；「device-side STT、語音永不上雲」改列為未來隱私強化方向。
> `POST /voice` 契約不變、仍只收文字——裝置先打 ASR 服務拿文字，再把文字送 `/voice`。
> 硬體對接契約見 [`requirements/hardware-integration.md`](requirements/hardware-integration.md)。
> **升級計時器必須放雲端**（Emergency Agent / Step Functions），不可留在 App/裝置，否則關機即失效。

> **聊天語音輸入是另一條線，不受此約束**：家屬／志工在自己的手機 App 上「按住說話」轉文字，
> 是使用者主動對自己的裝置錄音，音檔經 Edge Function `whisper` 代理送 OpenAI Whisper 做 ASR，
> 回傳文字填回輸入框、確認後才以純文字送出（`task_messages`）。這與「長輩端裝置影音永不上雲」
> 的隱私邊界（架構約束 1）互不衝突——邊界管的是**長輩端裝置**，不是 App 使用者主動的語音輸入。
> OpenAI 金鑰只存 Edge Function 的後端 secret（`OPENAI_API_KEY`），永不進前端封包。

雲端狀態機透過 **WebSocket / AppSync** 即時推播通知給三種使用者端，並依 **Cognito** 做角色區分。

**推播是雙軌的**（家屬要收到「疑似跌倒」、志工要收到派遣單，即使 App 沒開著）：
- **前景即時同步**：App 開著時，`SupabaseBackend` 訂閱 Supabase Realtime，事件／派遣單一變化就更新畫面並跳 App 內通知。AWS 平行環境的對應實作是 `AwsBackend`：每 3 秒打一次極輕量的 `/data/version` 取變更指紋，指紋變了才抓快照，且每次寫入後立刻強制刷新（取捨理由見 [`requirements/aws-architecture.md`](requirements/aws-architecture.md) §4.4）。兩者實作同一個 `BackendClient` 介面，由 `JinsunBackends` 依建置參數 `--dart-define=BACKEND` 選用，**UI 完全不知道自己連的是哪一套**。
- **背景系統推播**：App 在背景或關閉時，靠 **FCM（Android）＋ APNs（iOS）** 送系統通知。`radio_events` / `dispatch_tasks` 的 INSERT/UPDATE 觸發 Supabase **Database Webhook** → Edge Function [`send-push`](../cloud/supabase/functions/send-push/index.ts) → 依收件角色／綁定長輩查 `device_tokens` → FCM HTTP v1 發送（現行對應：SNS Mobile Push / Pinpoint）。

App 端由 `jinsun_core` 的 `PushService`（`apps/packages/core`）統一處理：登入後上報 FCM token 到 `device_tokens`、訂閱對應 topic、前景/背景/點擊訊息處理。**推播只承載事件文字，不含原始影音，與隱私邊界（約束 1）一致。** 接入所需的 Firebase／APNs 外部設定與資料流細節見 [`requirements/push-notifications.md`](requirements/push-notifications.md)。

### 使用者端

| 端 | 平台 | 角色 |
|---|---|---|
| 家屬 App | Flutter（Android／iOS） | 安心日報、緊急通知、**藍牙配對收音機（BLE Wi-Fi 佈建）**、**填寫長輩基本資料** |
| 志工 App | Flutter（Android／iOS） | 接單、時間銀行（真實時數）、可服務時段、證件狀態 |
| 社工 Web 後台 | Web（或 App） | 長輩表格（異常置頂）、督導人員、派遣監控、資料匯出 |

**資料模型新增（schema v1.1，見 `cloud/supabase/schema.sql`）**：
- `volunteers` 表補齊（原本 backend 有讀、schema 卻缺）＋ `service_hours`（可服務時段，JSON）。
- `volunteer_certificates` 表：良民證／志工意外險／基礎照護證書的狀態與效期。
- `elders.supervisor_worker_name` / `supervisor_volunteer_name`：每位長輩的督導社工／督導志工。
- 時間銀行時數改由 `time_bank_ledger` 加總（`backend.timeBankMinutesFor(name)`），非本 session 記憶體累加。

**長輩基本資料由家屬填寫（唯一真實來源）**：社工後台的長輩狀態卡、志工派遣單上的姓名／地址／電話／狀況注記，全部來自 `elders` 表，而這張表的內容由**家屬 App**填寫維護（設定頁 → 每台收音機 →「編輯長輩資料」，`ElderProfilePage`）。走 `backend.updateElderProfile()`（`BackendClient` 介面，Supabase／Mock 兩實作），寫 `elders` 後三端 Realtime 即時同步。家屬存檔時對地址做一次**地理編碼（OpenStreetMap Nominatim）**校正 `elders.lat/lng`，讓地圖釘與志工導航路線對到真實住址；查無座標則保留原值、只更新文字欄位。資料未補齊（地址／電話為空）時，設定頁該長輩卡會顯示「待補齊」提醒。

**收音機藍牙配對**：家屬 App 用 BLE（`flutter_blue_plus`）幫新收音機設定 Wi-Fi——搜尋→連線→選 Wi-Fi→傳密碼→裝置上網→以序號綁定。GATT 契約與 status 字串見 [`requirements/hardware-integration.md`](requirements/hardware-integration.md) §2；密碼只經 BLE 直傳、不上雲（不違反隱私邊界）。硬體模擬工具已移出社工後台前台導航（改用 `?sim=1` 進入）。

## 2. 跌倒偵測事件流程（Sequence）

以「疑似跌倒 → 語音確認 → 升級派遣 → 到場回報」為例：

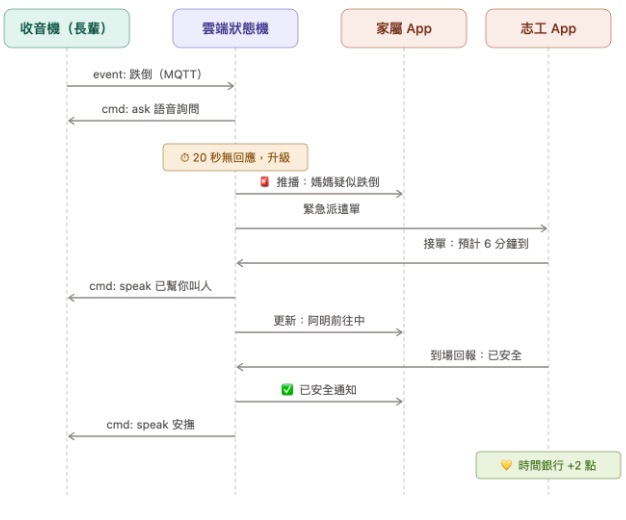
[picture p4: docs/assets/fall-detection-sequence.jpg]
跌倒偵測事件流程


1. 收音機偵測到跌倒事件，透過 MQTT 送出 `event: 跌倒`
2. 雲端狀態機下發 `cmd: ask`，收音機語音詢問長輩狀況
3. **20 秒無回應即升級**：
   - 推播「媽媽疑似跌倒」給家屬 App
   - 送出緊急派遣單給志工 App
4. 志工 App 接單，回報預計到達時間（如 6 分鐘）
5. 雲端狀態機下發 `cmd: speak`，收音機安撫長輩「已經幫你叫人」
6. 志工前往途中，家屬 App 即時收到位置更新
7. 志工到場回報「已安全」→ 雲端狀態機通知家屬「已安全」→ 收音機語音安撫
8. 志工的時間銀行點數 +2

**Bottleneck 提醒**：硬體事件要先穩定傳到雲端（MQTT），且各使用者端（家屬／志工）要能即時收到推播通知，這是整條鏈路能否在黃金時間內完成派遣的關鍵。

**下發指令類型**：原有 `ask`（語音詢問）、`speak`（播報／安撫）之外，語音 Agent server 的 Device Agent
新增裝置控制指令 `volume_up` / `volume_down` / `stop_speak` / `repeat`（對應長輩說「大聲一點／安靜／再說一次」）。

## 3. 角色與軟體類型對照

| 角色 | 需要看到／做到什麼 | 軟體類型 |
|---|---|---|
| 管理介面後台（社工／我們） | 所有即時狀態的 dashboard，需要「下載 Excel」以符合政府申報需求 | Web（或 App 皆可） |
| 家屬 | 掌握老人家即時狀態、接收緊急通知 | Flutter App（跨 Android／iOS，確保推播與易用性） |
| 志工 | 看到老人家需要什麼物資、接單去採買／到場確認安全 | Flutter App |
| 老人家 | 不需要 App，只需要收音機：跌倒偵測相機＋聲音偵測＋語音播報（是否需要幫助／還有多久會到）＋ SOS 時 TTS | 嵌入式裝置（無使用者介面學習成本） |

## 4. 隱私邊界（對應根目錄 README）

裝置端只在偵測到明確事件（SOS、語音求助、疑似跌倒）時才會將資料送上雲端；日常的提醒、關鍵字偵測、跌倒判斷皆在本地端完成，原始影像／聲音不上傳。這個邊界也反映在架構圖上：家中近端與 AWS 雲端之間的界線，是「只送事件不送影音」。

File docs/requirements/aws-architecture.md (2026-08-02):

# AWS 架構規劃（2026 AI 創新獎 · AWS 完整開發環境組）

> 對象：使用主辦方提供之 AWS 環境（含 Amazon Bedrock、SageMaker AI、Kiro）。
> 本文是**規劃書**，不是已完成的實作；`docs/architecture.md` 描述的是現況（Supabase + Render + 公共 MQTT broker）。
> 兩者的服務對應在 §3；落地順序在 §7。
> 架構圖：[`../assets/aws-architecture.drawio`](../assets/aws-architecture.drawio)；
> 評審備詢問答：[`aws-architecture-qa.md`](aws-architecture-qa.md)。

---

## 1. 現況盤點（要搬上 AWS 的東西）

| 現況元件 | 位置 | 型態 | 是否有狀態 |
|---|---|---|---|
| `POST /voice` HTTP 入口 | `cloud/prototype/src/server.js` | 常駐 Node HTTP server（Render） | 無 |
| Intent / Needs / Conversation / Device / Memory Agent | `cloud/prototype/src/agents/*` | 純函式 + LLM 呼叫 | 無 |
| **Emergency Agent 逾時階梯（8s → 12s → 升級）** | `cloud/prototype/src/agents/emergency.js` | `setTimeout` 在**行程記憶體**內 | **有（致命）** |
| 下行指令 push | `cloud/prototype/src/mqtt.js` | 內嵌 aedes／外部 mqttgo.io broker | 有（長連線） |
| 進度播報 worker | `cloud/prototype/src/progress.js` | 訂閱 Supabase Realtime 的常駐迴圈 | 有（長連線） |
| 志工移動模擬 | `cloud/prototype/src/travel.js` | 常駐 interval（demo 用） | 有 |
| LLM | `cloud/prototype/src/llm/bedrock.js` | 三供應商可切（apikey / bedrock / mock） | 無 |
| ASR（長輩端錄音） | 韌體直打 XCC Gateway Breeze-ASR | 外部 HTTP | 無 |
| ASR（App 聊天語音） | Supabase Edge Function `whisper` | Deno function | 無 |
| 資料層＋即時同步 | Supabase Postgres + Realtime + RLS | 託管 PG | 有 |
| 背景推播 | Supabase DB Webhook → Edge Function `send-push` → FCM/APNs | Deno function | 無 |
| 三端 UI | Flutter（家屬／志工 App、社工 Web） | 前端 | — |

**搬遷的三個技術難點，決定了整個架構：**

1. **20 秒升級計時器不能待在單一行程**（現在是 `setTimeout`）。行程重啟、擴容、當掉，黃金時間鏈路就斷。→ 必須落到 **Step Functions**。
2. **下行 push 需要裝置常駐連線**，但 PaaS 只開 443（Render 現在靠外部公共 broker 會合，無認證）。→ **IoT Core** 一次解決連線與憑證認證。
3. **資料層被三個 Flutter 端深度使用**（`SupabaseBackend` + Realtime 訂閱）。整包換掉是最大的一筆工。→ 拆成兩條 Track，先搬事件鏈路，資料層另計（§4.2）。

---

## 2. 目標架構總圖

> ⚠️ 這一節是**規劃**，不是現況。圖上的 Transcribe、Polly、AppSync、EventBridge、SNS、Guardrails
> **都還沒建**。要看實際跑著什麼、哪些線是通的，看 [§2.1 現況架構總圖](#21-現況架構總圖2026-08-01-實查)。

```mermaid
flowchart LR
  subgraph HOME["家中近端（不上雲）"]
    CAM["Himax WiseEye2<br/>跌倒推論（影像不外傳）"]
    MCU["AmebaPro2 / HUB8735<br/>主控·麥克風·喇叭·SOS 鍵"]
    CAM -->|本地事件| MCU
  end

  subgraph EDGE["裝置↔雲端邊界（只傳事件與文字）"]
    IOT["AWS IoT Core<br/>MQTT/TLS + X.509<br/>jinsun/{serial}/cmd｜/status"]
    APIGW["API Gateway (HTTP API)<br/>POST /voice"]
  end

  MCU -->|"① 上行 HTTPS（ASR 後文字／event）"| APIGW
  IOT -->|"② 下行 push（speak / ask / device）"| MCU
  MCU -.->|"錄音檔（僅主動觸發）"| ASR

  subgraph AI["AI 層"]
    ASR["Amazon Transcribe（國語）<br/>+ SageMaker Endpoint<br/>Breeze-ASR（台語）"]
    BR["Amazon Bedrock<br/>Claude Sonnet 4.6 / Haiku 4.5<br/>+ Guardrails"]
    TTS["Amazon Polly Zhiyu（國語）<br/>+ ATEN（台語，外部）"]
    SM["SageMaker AI<br/>跌倒模型訓練→量化→下發韌體"]
  end

  subgraph BRAIN["決策層"]
    ORCH["Lambda: orchestrator<br/>Intent/Needs/Conversation/Device/Memory"]
    SFN["Step Functions<br/>Emergency 逾時階梯<br/>8s → 12s → 升級"]
    PROG["Lambda: progress<br/>接單／接近 250m／抵達 → speak"]
  end

  subgraph DATA["資料與身分"]
    DB[("Aurora Serverless v2 (PostgreSQL)<br/>schema.sql 直接沿用")]
    DDB[("DynamoDB<br/>emergency_sessions · memory · device_shadow")]
    COG["Cognito<br/>家屬／志工／社工三角色"]
    S3[("S3<br/>語音暫存·Excel 匯出·靜態站台")]
  end

  subgraph FANOUT["推播與前端"]
    APPSYNC["AppSync<br/>GraphQL Subscription（前景即時）"]
    EB["EventBridge"]
    SNS["SNS Mobile Push<br/>APNs + FCM（背景通知）"]
    CF["CloudFront + S3<br/>社工後台 Flutter Web"]
  end

  APIGW --> ORCH
  ORCH --> BR
  ORCH --> SFN
  ORCH --> DDB
  SFN --> IOT
  SFN --> DB
  DB --> EB
  EB --> PROG
  EB --> SNS
  PROG --> IOT
  DB --> APPSYNC
  APPSYNC --> FAM["家屬 App"]
  APPSYNC --> VOL["志工 App"]
  CF --> ADMIN["社工後台"]
  SNS --> FAM
  SNS --> VOL
  COG -.-> APPSYNC
  COG -.-> APIGW
  ASR --> APIGW
  SM -.->|OTA| MCU
  ADMIN --> S3
```

**隱私邊界（架構約束 1）在圖上的位置**：`HOME` 與 `EDGE` 之間那條線。跨線的只有**事件與文字**，以及**長輩主動觸發**的那一段錄音（走 ASR）。影像永不跨線。

---

## 2.1 現況架構總圖（2026-08-01 實查）

**這張是實際跑著的東西**，每個節點都用 `aws` CLI 對 account `012804034919` / `us-west-2` 查證過，
不是規劃。與 §2 目標圖的差異列在圖後。

```mermaid
flowchart TB
  subgraph HOME["家中近端 · 影像不上雲"]
    CAM["Himax WiseEye2<br/>跌倒視覺推論<br/>（尚未實作）"]
    MCU["HUB8735 Ultra / AmebaPro2<br/>按鈕錄音 · TTS 播放 · SOS 鍵<br/>BACKEND_AWS = 1"]
    CAM -->|本地事件| MCU
  end

  subgraph EXT["外部服務 · 非 AWS"]
    XASR["XCC Gateway<br/>faster-whisper Breeze-ASR<br/>llm-gateway.xcc.tw"]
    XTTS["TTS<br/>kws.oaselab.org"]
  end

  MCU -->|"① 錄音（僅主動觸發）"| XASR
  XASR -->|文字| MCU
  XTTS -->|音檔串流| MCU

  subgraph AWS["AWS · us-west-2 · account 012804034919"]

    subgraph ENTRY["入口層"]
      APIGW["API Gateway HTTP API<br/>jinsun-voice-api · yr0ep335el"]
      IOT["IoT Core<br/>Thing JS-0001 / JS-REAL-0001<br/>JinsunDevicePolicy · X.509 雙向 TLS"]
      COG["Cognito User Pool<br/>jinsun-users · us-west-2_f34wIqjEd<br/>group: family / volunteer / worker"]
    end

    subgraph COMPUTE["運算層 · Lambda nodejs22.x"]
      LV["jinsun-voice<br/>六個 Agent：Intent / Emergency /<br/>Needs / Conversation / Device / Memory"]
      LD["jinsun-data<br/>三端資料 API + 角色授權"]
      LP["jinsun-progress<br/>進度播報去重"]
      LS["jinsun-speak<br/>下發一句話到裝置"]
      LA["jinsun-auth<br/>PreSignUp / PostConfirmation"]
    end

    subgraph ORCH["編排層 · Step Functions"]
      SFN1["JinsunEmergencyLadder<br/>絕對時間戳 8s → 20s 升級"]
      SFN2["JinsunEnrouteBroadcast<br/>路上每 10 分鐘"]
    end

    subgraph AI["AI 層"]
      BR["Bedrock<br/>Claude Sonnet 4.6<br/>Haiku 4.5"]
      SGM["SageMaker Endpoint<br/>breeze-asr-26 · 台語 ASR<br/>ml.g4dn.xlarge · InService"]
    end

    subgraph DATA["資料層"]
      AUR[("Aurora Serverless v2<br/>PostgreSQL 16.14 · Data API<br/>0.5–4 ACU · jinsun-aurora")]
      SM["Secrets Manager<br/>RDS 託管主密碼"]
      DDB[("DynamoDB<br/>jinsun_emergency_sessions<br/>jinsun_progress_announced<br/>jinsun_downlink（模擬器下行佇列）")]
      S3P[("S3 jinsun-proofs<br/>結案照片 · presigned PUT")]
    end

    subgraph WEB["前端託管"]
      S3W[("S3 ×4<br/>jinsun-family/volunteer/<br/>admin/elder-web")]
      CF["CloudFront ×4<br/>HTTPS 靜態站"]
      S3W --> CF
    end

    CW["CloudWatch Logs<br/>/aws/lambda/jinsun-*"]
  end

  MCU -->|"② POST /voice（文字或 event）"| APIGW
  IOT -->|"③ 下行 speak / ask<br/>jinsun/{serial}/cmd · QoS1"| MCU
  MCU -.->|"LWT jinsun/{serial}/status"| IOT

  APIGW -->|"$default（/voice · /asr · /commands · /health）"| LV
  APIGW -->|"/data/* ×4 · JWT authorizer"| LD
  LV -->|"POST /asr 代理<br/>x-bf-vk · PAT 只存 Lambda env"| XASR
  APIGW -.->|"POST /hooks/progress<br/>舊路徑 · 純 AWS 不走"| LP

  COG -.->|觸發器| LA
  LA --> AUR
  COG -.->|驗證 JWT| APIGW

  LV --> BR
  LV --> AUR
  LV --> DDB
  LV -->|StartExecution / StopExecution| SFN1
  SFN1 -->|"8s：語音詢問"| LS
  SFN1 -->|"20s：升級 → 開派遣單"| LV
  LS --> IOT

  LP --> IOT
  LP --> DDB
  LS -.->|tee 一份供模擬器| DDB
  ADM -.->|"GET /commands 長輪詢<br/>硬體模擬器 ?sim=1"| APIGW
  LP --> AUR
  LP -->|StartExecution| SFN2
  SFN2 -->|每 10 分鐘 tick| LP

  LD --> AUR
  LD --> S3P
  LD -->|"接單／抵達／座標變化<br/>非同步 invoke（取代 Realtime 訂閱）"| LP
  AUR -.-> SM

  LV -.-> CW
  LD -.-> CW
  LP -.-> CW

  CF --> FAM["家屬 App<br/>Flutter Web"]
  CF --> VOL["志工 App<br/>Flutter Web"]
  CF --> ADM["社工後台<br/>Flutter Web"]
  CF --> ELD["長輩端收音機（網頁版）<br/>elder_app · Flutter Web<br/>Cognito 裝置帳號自動登入"]
  FAM -->|"每 3 秒 /data/version 變更指紋"| APIGW
  VOL --> APIGW
  ADM --> APIGW
  ELD -->|"POST /asr → POST /voice<br/>＋ /data/* 輪詢"| APIGW

  SGM -->|"OpenAI 相容門面<br/>jinsun-asr-openai（SigV4 重簽）"| MCU

  classDef notwired stroke-dasharray: 5 5
  class CAM notwired
```

### 用到哪些 AWS 服務、分別用在哪

| AWS 服務 | 實際資源 | 用在什麼地方 |
|---|---|---|
| **API Gateway**（HTTP API） | `jinsun-voice-api` / `yr0ep335el` | 唯一的 HTTPS 入口。8 條路由：`$default`→語音（含 `POST /voice`、`POST /asr`、`GET /health`、`GET /commands`）、`POST /hooks/progress`→進度、`/data/{version,snapshot,mutate,timebank}`→資料 API（掛 JWT authorizer）、`POST /tts`＋`OPTIONS /tts`→國語 TTS（**無 authorizer**，同 `/asr` 的理由）。`/asr` 沒有獨立路由也**沒有 JWT authorizer**——它落在 `$default` 上，長輩端是裝置身分，不該為了轉一句逐字稿去換 token |
| **Lambda** ×7 | `jinsun-voice` `jinsun-data` `jinsun-progress` `jinsun-speak` `jinsun-auth` `jinsun-tts` `jinsun-asr-openai` | 全部商業邏輯。`voice` 跑六個 Agent；`data` 是三端資料 API＋角色授權；`progress` 播報去重；`speak` 只做「publish 一句話到 IoT」；`auth` 是 Cognito 觸發器；`tts` 是國語語音合成（Polly Zhiyu）；`asr-openai` 是 SageMaker 的 OpenAI 相容門面。後兩支是唯一兩套環境共用的（無狀態、無資料落地） |
| **Step Functions** ×2 | `JinsunEmergencyLadder`、`JinsunEnrouteBroadcast` | **黃金 20 秒鏈路**。取代原本行程內的 `setTimeout`／`setInterval`——行程重啟也不會漏升級。用絕對時間戳而非相對 `Wait`（相對會累積開銷，實測超窗到 21.55s） |
| **IoT Core** | Thing `JS-0001`／`JS-REAL-0001`、policy `JinsunDevicePolicy` | 下行指令 push（`jinsun/{serial}/cmd`）、裝置上下線 LWT。X.509 雙向 TLS，取代正式環境那顆無認證的公共 broker |
| **Aurora Serverless v2** | `jinsun-aurora`、PG 16.14、Data API、0.5–4 ACU | 唯一的關聯式資料庫，與正式環境 Supabase **完全斷開**。走 Data API 所以 Lambda 不必進 VPC。最小容量刻意設 0.5 而非 0（從零擴容約 15 秒，會吃掉黃金窗） |
| **DynamoDB** ×3 | `jinsun_emergency_sessions`、`jinsun_progress_announced`、`jinsun_downlink` | 三張都有 TTL。第一張存急救 session（誰在等回應、Step Functions execution ARN），第二張做播報去重（同一張單不重複念），第三張是**下行扇出佇列**——`jinsun-speak`／`jinsun-progress` publish 到 IoT 的同時複製一份，供瀏覽器版模擬器（`admin/?sim=1`）用 `GET /commands` 長輪詢領取（真裝置不走這條，它收 MQTT push） |
| **Cognito** | User Pool `jinsun-users`、Client `jinsun-apps`、3 個 Group | 三端身分與角色。**角色只認 `cognito:groups`**，不認 `custom:role`（後者使用者自己就能改）。取代 Supabase Auth + RLS。長輩端多一個**裝置帳號** `device-js-0001@jinsun.local`（group `family`，只綁 elder-1）——長輩端沒有 UI，不可能叫長輩登入，帳密在 build 時注入、開網頁自動登入 |
| **Bedrock** | `us.anthropic.claude-sonnet-4-6`、`claude-haiku-4-5` | 六個 Agent 的大腦（意圖分類、需求解析、陪伴對話）。此帳號只授權這兩顆，裸 model id 一律 `ResourceNotFound`，必須帶 `us.` 前綴 |
| **SageMaker** | Endpoint `breeze-asr-26`、`ml.g4dn.xlarge` | 台語／國語 ASR（Transcribe 無台語）。✅ **已接線**（commit `f5cba93`）：SageMaker 強制 SigV4 簽章、HUB8735 做不到，改由 `jinsun-asr-openai` Lambda 開成 OpenAI 相容的 `POST /v1/audio/transcriptions`，韌體 `api_server` 已指向它、組請求的程式碼一行未動。XCC Gateway 降為註解掉的備援 |
| **S3** ×5 | `jinsun-proofs`、`jinsun-{family,volunteer,admin,elder}-web` | 結案照片（presigned PUT，志工直傳不經 Lambda）＋四端 Flutter Web 靜態站 |
| **CloudFront** ×4 | `E2A1BW0EZXSZWA`／`E1SO2GTWWKONH8`／`E4QI5MMFZRZ5A`／`E1QH4VWLX0WN30`（elder） | 四端 HTTPS。**必須用 CloudFront 網址**，S3 網站端點只有 HTTP，瀏覽器在非 HTTPS 下不給定位權限，志工 GPS 上報會整條失效；長輩端更嚴重——麥克風同樣要 HTTPS，走 S3 端點的話大錄音按鈕整個是啞的 |
| **Secrets Manager** | `rds!cluster-b4211a31-…` | Aurora 主密碼，由 RDS 託管（`--manage-master-user-password`），無人經手 |
| **IAM** ×6 role | `JinsunVoice/Progress/Speak/Data/Auth LambdaRole`、`JinsunEmergencyLadderRole` | 每支 Lambda 一個最小權限 role |
| **CloudWatch Logs** | `/aws/lambda/jinsun-*` ×7 | 唯一的除錯入口。⚠️ **retention 未設＝永久保留**，賽後清理要記得 |

### 2.1.1 四條主要流程（服務之間怎麼走）

上面那張圖畫的是「誰連到誰」，這一節畫的是「一次事件依序發生什麼」。四條流程涵蓋
所有服務間的實際呼叫，**沒有出現在這四張圖裡的連線就是還沒接線的**。

#### 流程 A — 長輩主動求助／代辦（唯一會上雲的語音）

長輩端有兩種載體：實體收音機（韌體自己打 XCC）與網頁版 `elder_app`（經 `/asr` 代理，
金鑰不進前端）。上雲的只有「長輩主動按下按鈕」那一段，符合架構約束 1。

```mermaid
sequenceDiagram
  autonumber
  participant E as 長輩端<br/>（韌體／elder_app）
  participant GW as API Gateway
  participant LV as jinsun-voice
  participant X as XCC Gateway<br/>（外部）
  participant BR as Bedrock
  participant AU as Aurora

  Note over E: 按住大按鈕錄音（WAV 16k mono）
  alt 網頁版 elder_app
    E->>GW: POST /asr { audio_base64 }
    GW->>LV: $default
    LV->>X: multipart（x-bf-vk）
    X-->>LV: { text }
    LV-->>E: { text }
  else 實體收音機
    E->>X: 直接打（PAT 燒在 secrets.h）
    X-->>E: { text }
  end

  E->>GW: POST /voice { device_serial, text }
  GW->>LV: $default
  LV->>BR: 意圖分類（Haiku 4.5）
  BR-->>LV: emergency / need / device / general
  alt need（我想買牛奶跟雞蛋）
    LV->>AU: 開物資派遣單
  else general（閒聊）
    LV->>BR: 陪伴對話（Sonnet 4.6）
  end
  LV->>AU: 查偏好語言（國語／台語）
  LV-->>E: { reply, intent, lang }
  Note over E: 念出 reply（雲端 TTS，打不通退回本機語音）
```

#### 流程 B — 疑似跌倒／SOS → 20 秒黃金升級（本系統最重要的一條）

計時器在 Step Functions，不在行程內 —— Lambda 執行完就結束了，`setTimeout` 根本活不到 20 秒。

```mermaid
sequenceDiagram
  autonumber
  participant E as 長輩端
  participant LV as jinsun-voice
  participant SF as Step Functions<br/>JinsunEmergencyLadder
  participant LS as jinsun-speak
  participant IOT as IoT Core
  participant AU as Aurora
  participant DD as DynamoDB<br/>sessions
  participant APP as 家屬／志工／社工

  E->>LV: POST /voice { event: fall_suspected }
  LV->>AU: 開「AI 詢問中」事件列（不等 20 秒，三端立刻看得到）
  LV->>SF: StartExecution（帶絕對時間戳 step1At / escalateAt）
  LV->>DD: 存 executionArn（供「我沒事」解除）
  LV-->>E: 「您還好嗎？」

  alt 長輩在 20 秒內回「我沒事」
    E->>LV: POST /voice { text: "我沒事" }
    LV->>DD: 取回 executionArn
    LV->>SF: StopExecution（整條鏈路中止）
    LV-->>E: 安撫語，結束
  else 逾時無回應
    SF->>SF: Wait 到 step1At（8s）
    SF->>LS: SpeakStep1
    LS->>IOT: publish jinsun/{serial}/cmd（QoS1）
    IOT->>E: 再問一次
    SF->>SF: Wait 到 escalateAt（+12s ＝ 共 20s）
    SF->>LV: Escalate（__sfn）
    LV->>AU: 事件升級 emergency ＋ 開緊急派遣單、指派最近志工
    AU-->>APP: 三端輪詢 /data/version 指紋變化 → 抓快照 → 跳通知
    SF->>LS: SpeakOnEscalated
    LS->>IOT: 「志工已經在路上」
    IOT->>E: 播報安撫
  end
```

> ⚠️ `Wait` 用的是**絕對時間戳**（`step1At` / `escalateAt`）而不是相對秒數。相對 `Wait`
> 會把每次狀態轉場的開銷累積進去，實測會超出黃金窗（21.55s）。

#### 流程 C — 志工接單 → 到場 → 結案 → 時間銀行

Aurora 沒有 Realtime，所以「資料庫變更要觸發播報」是靠 `jinsun-data` 寫完之後
**直接非同步 invoke** `jinsun-progress`，不是資料庫觸發器。

```mermaid
sequenceDiagram
  autonumber
  participant V as 志工 App
  participant GW as API Gateway
  participant LD as jinsun-data
  participant AU as Aurora
  participant LP as jinsun-progress
  participant DD as DynamoDB<br/>announced
  participant SF as Step Functions<br/>JinsunEnrouteBroadcast
  participant IOT as IoT Core
  participant E as 長輩端
  participant S3 as S3 jinsun-proofs

  V->>GW: POST /data/mutate { op: acceptTask }（JWT）
  GW->>LD: JWT authorizer 驗過 → 帶 cognito:groups
  LD->>AU: 更新派遣單（含擁有權檢查，搶單衝突回 409）
  LD-)LP: 非同步 invoke { __direct: accepted }
  LP->>DD: 查去重（同一張單不重複念）
  LP->>IOT: 「志工阿明正在過來，大約 8 分鐘到」
  IOT->>E: 播報
  LP->>SF: StartExecution（路上每 10 分鐘回報一次）
  loop 每 10 分鐘，直到不再是 enroute
    SF->>LP: Tick
    LP->>AU: 還在路上嗎？
    LP->>IOT: 進度播報
  end

  V->>GW: POST /data/mutate { op: markArrived }
  LD-)LP: 非同步 invoke { __direct: arrived }
  LP->>IOT: 「志工到您家門口了」

  Note over V,S3: 結案照片不經 Lambda
  V->>GW: 要一組 presigned PUT URL
  LD-->>V: presigned URL
  V->>S3: PUT 照片位元組（直傳）
  V->>GW: POST /data/mutate { op: resolveTask }
  LD->>AU: 結案 ＋ 時間銀行 +21 分、長輩燈號回綠
```

#### 流程 D — 四端即時同步與身分（為什麼是輪詢不是訂閱）

```mermaid
sequenceDiagram
  autonumber
  participant A as 四端 Flutter Web<br/>家屬／志工／社工／長輩
  participant COG as Cognito
  participant GW as API Gateway
  participant LD as jinsun-data
  participant AU as Aurora

  alt 家屬／志工／社工
    A->>COG: InitiateAuth（手機號碼 → {digits}@jinsun.local）
  else 長輩端 elder_app
    A->>COG: InitiateAuth（裝置帳號，帳密由 build 時注入，長輩無感）
  end
  COG-->>A: IdToken（含 cognito:groups）

  loop 每 3 秒
    A->>GW: GET /data/version（帶 Bearer）
    GW->>LD: JWT authorizer
    LD->>AU: 取六張表的 md5 指紋
    LD-->>A: { v: {elders, events, tasks, ...} }
    alt 指紋沒變
      Note over A: 什麼都不做（絕大多數情況）
    else 指紋變了
      A->>GW: GET /data/snapshot
      LD->>AU: 依角色套 SQL 述詞<br/>家屬只看綁定的長輩／志工看自己的單或搶單池／社工全看
      LD-->>A: 已過濾的快照 → 跳通知
    end
  end
```

> 為什麼不用 AppSync 訂閱：跌倒升級開單是後端 Lambda **直接寫 Aurora** 的，不經過
> AppSync mutation，訂閱對「最重要的那條鏈路」根本不會響。要響就得讓每支後端 Lambda
> 反手再呼叫一次 AppSync，多一層耦合換 3 秒 → 次秒級。這個系統的黃金窗是 20 秒，
> 3 秒的偵測延遲綽綽有餘。詳見 §4.4。

### 與 §2 目標圖的差異（＝還沒做的）

| 目標圖上有 | 現況 |
|---|---|
| Transcribe（國語 ASR） | **沒用**。國語 ASR 走外部 XCC Gateway：韌體直接打，長輩端網頁版則經 `jinsun-voice` 的 `POST /asr` 代理（金鑰不進前端封包）。刻意不換 Transcribe——它沒有台語，而這條是長輩唯一的輸入方式 |
| Polly（國語 TTS） | ✅ **已接**（`jinsun-tts` Lambda，`POST /tts`，Zhiyu neural → WAV）。台語仍走外部 `kws.oaselab.org`（ATEN 是台語模型，Polly 沒有閩南語音色），裝置端依 `speak.lang` 分流 |
| SageMaker 台語 ASR | ✅ **已接線**（`jinsun-asr-openai` 門面 + 韌體已切換），本列保留供對照 |
| SageMaker 跌倒模型訓練 → OTA | **沒做**。跌倒視覺推論本身尚未實作 |
| AppSync GraphQL Subscription | **沒建**。改用 `/data/version` 變更指紋輪詢（每 3 秒），取捨理由見 §4.4 |
| EventBridge | **沒建**。播報改由 Step Functions 迴圈驅動 |
| SNS Mobile Push | **沒建**。`device_tokens` 已會寫進 Aurora，發送端還沒接 |
| Bedrock Guardrails | **沒設** |
| 資料庫變更 → 播報 | ✅ **已補上**（2026-08-01）。原本 `POST /hooks/progress` 在 API Gateway 上存在但全 repo 沒有呼叫者，且 `jinsun-progress` 因殘留 `@supabase/supabase-js` import 而**載入即失敗**——整條播報鏈路是死的。現改為 `lambda/data/ops.mjs` 的 `acceptTask`／`markArrived`／`setVolunteerLocation` 寫完 Aurora 後**直接非同步 invoke** `jinsun-progress`（`event.__direct`）。詳見 [handoff §5](aws-handoff.md) |

---

## 3. 服務對應表（現況 → AWS）

### 3.1 事件與語音鏈路

| 現況 | AWS 正式服務 | 遷移成本 | 備註 |
|---|---|---|---|
| `POST /voice`（Render 常駐） | **API Gateway HTTP API + Lambda** | 低 | handler 直接包現有 `orchestrator.handle()`；契約（`device_serial` / `text` / `event` / `reply`）完全不變，韌體只換 `BASE_URL` |
| aedes / mqttgo.io broker | **AWS IoT Core** | 中 | topic `jinsun/{serial}/cmd`、payload 完全不變；改 endpoint + 燒 X.509 憑證。**同時解掉「公共 broker 無認證」的資安洞** |
| 上下線偵測（LWT） | **IoT Core Lifecycle Events** → EventBridge → Lambda | 低 | 免自己維護心跳，後台「裝置離線」直接訂閱 `$aws/events/presence/disconnected/{clientId}` |
| **Emergency 逾時階梯**（`setTimeout`） | **Step Functions（Standard）** | 中 | 見 §4.1，這是本案最關鍵的一塊 |
| `progress.js`（Supabase Realtime worker） | **EventBridge Pipes → Lambda**（來源：Aurora 變更 or DynamoDB Streams） | 中 | 志工接單／接近 250m／抵達 → publish 到 IoT Core |
| `travel.js`（demo 志工移動模擬） | **EventBridge Scheduler + Lambda** | 低 | 每 N 秒觸發一次寫座標，demo 專用 |
| LLM（XCC Gateway） | **Amazon Bedrock**（Claude Sonnet 4.6 / Haiku 4.5，實測可用） | **極低** | `llm/bedrock.js` 已經寫好 provider 切換，改 `LLM_PROVIDER=bedrock` 即可；見 §5.1 |
| ASR（Breeze-ASR via XCC） | **Transcribe（zh-TW）＋ SageMaker Endpoint（台語 Breeze-ASR）** | 中 | 見 §5.2 |
| TTS（ATEN，台語） | **Amazon Polly（國語）＋ ATEN 續留（台語）** | ✅ **已完成** | ATEN 是台語模型且端點不吃 voice 參數，換不了國語 → 補 `jinsun-tts`（Polly Zhiyu）走 `lang=mandarin`。Polly 無閩南語音色，台語沒有理由搬 |
| Edge Function `whisper`（App 聊天語音） | **API Gateway + Lambda → Transcribe** | 低 | 金鑰改用 IAM role，不再需要代理外部 API key |
| Edge Function `send-push` → FCM | **SNS Mobile Push（Platform Application: APNs + FCM）** | 中 | 由 EventBridge 規則觸發 Lambda 決定收件者，再 `sns:Publish` 到 endpoint／topic |

### 3.2 資料、身分、前端

| 現況 | AWS 正式服務 | 遷移成本 | 備註 |
|---|---|---|---|
| Supabase Postgres（`schema.sql` 14 張表 + trigger） | **Aurora Serverless v2 (PostgreSQL 16)** | 中 | `schema.sql` 幾乎可原封執行（`gen_random_uuid()`／`jsonb`／trigger 都相容）；只需拿掉 `auth.users` 外鍵改指 Cognito `sub` |
| Supabase Realtime（三端訂閱） | ~~AppSync~~ → **API Gateway + `jinsun-data` Lambda ＋變更指紋輪詢** | 中 | 已實作。改採輪詢的理由見 §4.4；三端共用 `AwsBackend extends BackendClient` |
| Supabase Auth + RLS | **Cognito User Pool（三個 Group：family / volunteer / worker）** | 中 | 已實作。RLS 改寫成 `cloud/aws/lambda/data/authz.mjs` 的讀取述詞＋寫入白名單 |
| 記憶體 Map（Emergency session、Memory Agent） | **DynamoDB**（`emergency_sessions`、`elder_memory`） | 低 | PK = `elderKey`，Emergency session 加 TTL 自動清 |
| 社工後台 Flutter Web | **S3 + CloudFront（OAC）** | 低 | `flutter build web` → `aws s3 sync` |
| Excel 匯出（政府硬需求） | **Lambda 產 xlsx → S3 → Presigned URL** | 低 | 大量資料改走 **Athena over S3 Parquet**；見 §5.4 |
| 裝置配網後的登錄 | **IoT Core Fleet Provisioning + Lambda pre-provisioning hook** | 中 | 家屬 App BLE 配網 → 裝置憑證自動簽發 → 寫 `elders.device_serial` |

---

## 4. 三個關鍵架構決策

### 4.1 決策一：20 秒升級計時器 → Step Functions（**必做**）

現在的計時器活在 `emergency.js` 的 `setTimeout`。這違反架構約束 3 的精神：**計時器必須存活於任何單一行程的生命週期之外**。

**目標狀態機**（✅ 已實作並實測，見 §11.3）：

```
POST /voice（Lambda）
  ├─ 同步回 reply = EMERGENCY_SCRIPT.onStart  → 裝置立刻播（不經 MQTT）
  ├─ 寫 radio_events(status=attention)        → 三端立刻亮「AI 確認中」
  └─ StartExecution，input 帶「絕對時間戳」：
         step1At    = T0 + 8s
         escalateAt = T0 + 20s     （T0 = 長輩聽到第一句的時刻）

狀態機（StartAt = Wait，不重播 onStart）
  ├─ Wait  → TimestampPath: $.step1At
  ├─ SpeakStep1  (Lambda: jinsun-speak → IoT Publish)  「我沒有聽到您的聲音…」
  ├─ Wait  → TimestampPath: $.escalateAt
  ├─ Escalate (Lambda)  寫 dispatch_tasks(kind=emergency) → 觸發三端推播，回傳 etaMinutes
  └─ SpeakOnEscalated (Lambda: jinsun-speak) 「志工已在路上，大約 N 分鐘到…」
```

**三個實作上必須注意的點（都是實測踩出來的，見 §11.3）：**

1. **`onStart` 不要放進狀態機。** 它是 `POST /voice` 的同步 HTTP 回覆（`emergency.js` 就是這樣寫的：
   `return { reply }` 之後才 `armLadder()`）。狀態機若再播一次會重複，且把整條鏈路往後推 2 秒。
   狀態機的 `StartAt` 直接是第一個 Wait。

2. **Step Functions 不能直接 publish 到 MQTT。** AWS SDK 整合清單裡有 `iot`（控制面）、
   `iotjobsdataplane`、`ioteventsdata`，**沒有 IoT Data Plane**——`arn:aws:states:::aws-sdk:iotdata:publish`
   會 `SCHEMA_VALIDATION_FAILED`。必須經一支 Lambda（`jinsun-speak`）代打 `IoTDataPlaneClient.publish`。
   這不算繞路：`Escalate` 那步本來就需要 Lambda 寫資料庫。

3. **用絕對時間戳，不要用相對 `Seconds`。** 相對 Wait 會讓每一步的轉場開銷（StartExecution、
   state transition、Lambda invoke）**累積**，實測升級落在 21.55s、**超窗 1.55s**。
   改成 `TimestampPath` 後，各步偏差彼此獨立且有界，升級穩定落在 T0+20.0s。

**解除（長輩說「我沒事」）**：`POST /voice` 的 Lambda 收到解除詞時，用 DynamoDB 存的 `executionArn`
呼叫 `states:StopExecution`。✅ 已實測：execution 轉為 `ABORTED`，後續 25 秒收音機零指令。
不用 task token、不用輪詢，一行 API 就停掉整條升級鏈——比現在的 `clearTimeout` 更可靠（跨行程有效）。

**為什麼是 Standard 不是 Express**：Standard 有完整執行歷史（評審／稽核可看每一階的時間戳，
§11.3 那張表就是直接從 `get-execution-history` 拉出來的），且 20 秒鏈路量極小，
成本可忽略（$0.025 / 1000 state transitions，一天 100 次事件 ≈ $0.02/月）。

### 4.2 決策二：資料層 → 分兩條 Track，不要一次搬

三個 Flutter 端全部建在 `SupabaseBackend` + Realtime 之上。一次換掉是這個專案最大的單一風險。

| 方案 | 工作量 | schema 可攜性 | 評分（AWS 服務串接） | 建議 |
|---|---|---|---|---|
| 留 Supabase | 0 | — | 低 | 只作為 Track A 期間的過渡 |
| **Aurora Serverless v2 + AppSync + Cognito** | 中 | **高**（`schema.sql` 幾乎原封） | 高 | ✅ **推薦** |
| DynamoDB + AppSync + Cognito | 高 | 低（14 張關聯表要重新設計 single-table） | 高 | 規模化後再考慮；hackathon 期間 CP 值低 |

**推薦理由**：`cloud/supabase/schema.sql` 是關聯式設計（外鍵、trigger、enum、`text[]`、`jsonb`），Aurora PostgreSQL 幾乎零改寫；把預算花在 AppSync 訂閱與 Cognito 授權上，而不是重畫資料模型。DynamoDB 只用在**真正 key-value 的三塊**：Emergency session、長輩長期記憶、裝置 shadow。

Aurora Serverless v2 現已支援 **scale-to-zero（min 0 ACU）**，閒置時段不計費，適合 demo 型專案。

### 4.3 決策三：運算層 → App Runner 保底 + Lambda 主線（**兩者並存**）

> ⚠️ **本節的「App Runner 保底」後來被推翻了，別照著做。** 實測 `apprunner:ListServices`
> 在帳號 012804034919 被 **SCP 擋下**（帳號層級政策，不是權限設定），App Runner 在此帳號根本開不起來。
> `deploy/aws/` 的容器部署已改寫成 ECS Fargate + ALB，但**同樣未實跑過**。
> **實際可用的保底是 Render 那台**（`jinsun-voice-server-mg1f.onrender.com`，仍在運行、連正式 Supabase），
> 韌體把 `#define BACKEND_AWS` 改回 `0` 就切回去。詳見 `aws-handoff.md` §6.3／§6.4。
> 以下保留原始推論以記錄「為什麼主線可以走 Lambda」——那部分的結論仍然成立。

`cloud/prototype/Dockerfile` 已經存在且開頭就寫著「不能放 serverless」。這句話在 IoT Core 之後**部分失效**了：

- 「20 秒計時器」→ 移交 Step Functions ✅
- 「`/commands` 長輪詢」→ demo 模擬器專用，正式鏈路走 IoT Core ✅
- 「進度播報 worker 訂閱 Realtime」→ 移交 EventBridge → Lambda ✅

三個「必須常駐」的理由都被拆掉了，所以主線可以走 Lambda。

**但仍建議同時保留 App Runner**：

| 用途 | 服務 | 理由 |
|---|---|---|
| **主線（評審看的）** | API Gateway + Lambda + Step Functions + IoT Core | 符合「串接多項雲端服務」，且無伺服器維運 |
| **保底（demo 當天的保險）** | **App Runner** 跑現有 `Dockerfile` | 零程式改動、10 分鐘上線；主線出問題時把韌體 `BASE_URL` 切回來即可。它同樣能連 IoT Core（出站 8883 沒問題），所以下行不受影響 |

> App Runner 與 Render 一樣只開對外 443、內嵌 broker 進不來——但改用 IoT Core 後這個限制完全消失，因為裝置是主動連 IoT Core，server 只是另一個 publish 端。**這是搬到 AWS 最直接的一個收益。**

### 4.4 決策四：三端即時同步 → 變更指紋輪詢，**不是** AppSync 訂閱

原規劃是 AppSync GraphQL Subscriptions 對應 `BackendClient` 的 8 個 `Stream`。實作時改掉了，理由有三個，第一個是決定性的：

1. **訂閱對最重要的那條鏈路不會響。** AppSync 的 subscription 只在「經過 AppSync 的 mutation」時觸發。
   但疑似跌倒 20 秒逾時升級、開派遣單，是 Step Functions 叫 `jinsun-voice` Lambda **直接寫 Aurora** 的
   （黃金時間鏈路刻意不繞路）。要讓訂閱響，就得讓每一支後端 Lambda 在寫完資料庫之後，
   反手再呼叫一次 AppSync 的 publish mutation——多一個相依、多一個失敗點，
   而且那個失敗點正好落在系統最不能失敗的地方。
2. **這個系統的即時性標準是 20 秒，不是 200 毫秒。** 黃金窗是「疑似跌倒 → 20 秒無回應 → 升級」，
   3 秒的偵測延遲在其中佔 15%，且**寫入方自己永遠是即時的**（見下）。
   `SupabaseBackend` 本來就有一條 8 秒的保底輪詢在跑，這條路徑是驗證過的。
3. 交接當下 AWS 憑證已過期，AppSync 無法實際部署驗證；一套沒跑過的訂閱鏈路不該進 demo。

**實際做法**（`cloud/aws/lambda/data/index.mjs` + `apps/packages/core/lib/src/aws_backend.dart`）：

| 端點 | 用途 |
|---|---|
| `GET /data/version` | 六張表的變更指紋（每張一個 md5）。App 每 3 秒打一次，**指紋沒變就不抓快照** |
| `GET /data/snapshot` | 一次回全部集合，**單次 Data API 往返**（用 `json_agg` 把六張表包成同一列） |
| `POST /data/mutate` | 具名寫入操作 `{op, args}`，可寫欄位寫死在 `ops.mjs` |

兩個設計細節：

- **指紋不是 `count(*)` + `max(時間)`。** 事件從 `open` 翻成 `escalated`、長輩燈號從 `normal` 翻成
  `emergency`，這兩件事都不新增列、也不動時間欄位——但它們正是最需要立刻反映到三端的變化。
  所以指紋涵蓋「會影響畫面的欄位」本身。
- **每次寫入之後立刻強制抓一次快照。** 所以 3 秒只發生在「別人動的」，
  使用者自己按下去的動作永遠是即時的。

日後若要升級成真訂閱，介面不必動：`AwsBackend` 對外仍是那 8 個 `Stream`，
只要把 `_tick()` 換成訂閱回呼即可。

### 4.5 授權：RLS 的等價規則落在哪裡

原環境的 RLS 其實是 **demo 全開**（`for select using (true)`），不能照搬也不值得照搬。
AWS 這側重寫在 `cloud/aws/lambda/data/authz.mjs`，分兩層：

- **讀**：角色 → SQL 述詞。家屬只看得到 `family_bindings` 綁定的長輩及其事件／派遣單／訊息；
  志工只看得到指派給自己的單，或已開放搶的單（緊急單 pending 即全體可見、物資單要過寬限期、
  追蹤單永不進搶單池）；社工全看。**沒有角色＝什麼都看不到**（預設拒絕）。
- **寫**：op → 允許角色的白名單，再加擁有權檢查（只有接單志工能改 ETA、只能改自己的志工資料、
  看不到的單不能結案）。未知 op 一律拒絕。

兩個刻意的收緊：

- **社工角色不能自助註冊。** `worker` 在授權表裡是「全看、全改」，如果註冊表單自己選就能當社工，
  整套授權等於沒做。`jinsun-auth` 的 PostConfirmation 只接受 `family` / `volunteer`，
  其餘一律退回 `family`；社工由管理者 `admin-add-user-to-group`。
- **時間銀行點數由伺服器算。** 結單點數依 `kind` 與 `eta_minutes` 在 Lambda 內算
  （與 Dart `models.dart` 的 `timeBankMinutes` 同一套算法），不收客戶端送來的數字。

角色一律以 **Cognito Group** 為準（token 的 `cognito:groups`），不看自訂屬性——
自訂屬性使用者自己就能改。

---

## 5. Bedrock / SageMaker AI / Kiro 在本案的具體用途

（此組別的評分重點，每一項都對應到 repo 裡真實存在的需求，不是硬湊）

### 5.1 Amazon Bedrock — 語音多 Agent 的大腦

`cloud/prototype/src/llm/bedrock.js` 已經預留好切換點，落地成本最低。

> ✅ **已在主辦帳號實測（2026-08-01，account `012804034919` / `us-west-2` / `WSParticipantRole`）**。
> 下表的 model id 是**實際打通的**，不是查表推測的。

| 用途 | 模型（實測可用） | 實測延遲 | 對應現有程式 |
|---|---|---|---|
| Intent 分類（快、量大、要便宜） | `us.anthropic.claude-haiku-4-5-20251001-v1:0` | — | `agents/intent.js`（`fast: true` 那條路） |
| 陪伴對話、需求解析 | `us.anthropic.claude-sonnet-4-6` | 2.7–3.2s | `agents/conversation.js`、`agents/needs.js` |

⚠️ **此帳號未授權 Opus 5 / Sonnet 5 / Opus 4.8 / Fable 5**（`AccessDeniedException`）。
本文初稿建議的 `anthropic.claude-opus-5` **不可用**，已改為 Sonnet 4.6。
⚠️ **裸 foundation model id 一律 `ResourceNotFoundException`**（例如 `anthropic.claude-3-haiku-20240307-v1:0`）——
**必須走 inference profile**，也就是帶 `us.` 或 `global.` 前綴的 id。`BEDROCK_MODEL_ID` 請務必填前綴版本。

**實測延遲對黃金窗的意義**：同步回覆 2.7–3.2s，遠小於逾時階梯第一階的 8s，
所以 `/voice` 的 `reply` 走 Bedrock 不會擠壓升級鏈路。Sonnet 4.6 省略 `thinking` 參數即不思考，
這正是 `/voice` 同步回覆要的行為（不要為了品質開 adaptive thinking，那會把延遲推進危險區）。

**實測發現並已修正的兩個 prompt 問題**（切 Bedrock 後才浮現，`agents/conversation.js`
與 `agents/needs.js` 兩支的 system prompt 都已補上，41 個既有測試全數通過）：

1. **長輩稱謂**：Sonnet 4.6 預設會用「阿公／阿嬤」稱呼長輩，違反專案已定案的
   **移除稱謂、一律以「您」相稱**（見 `src/progress.js` 註解）。
2. **表情符號**：模型會在回覆結尾加 emoji（如「…透透氣？😊」）。**這段文字會直接送進 TTS**，
   emoji 念出來是雜音或被跳過。prompt 已明確禁止 emoji／顏文字／Markdown／括號註記，只允許一般標點。

> 切換 LLM 供應商後**務必重跑語氣驗收**——這兩個問題在 XCC Gateway 上不明顯，換 Bedrock 才出現。
> 驗收方式：對最容易誘發的十句（天氣、想念家人、節慶祝賀、身體不適…）打 `/voice`，
> 用 regex 檢查回覆不含 `阿公|阿嬤|爺爺|奶奶|老人家` 與 emoji 碼位。實測 10/10 通過。
| **Bedrock Guardrails** | — | 對長輩的輸出加安全護欄（醫療建議、金融詐騙誘導、自傷內容）——這是「服務對象是失能長者」必須有的一層 |
| **Bedrock Knowledge Bases** | Titan Embeddings + OpenSearch Serverless | 取代 `agents/memory.js` 現在的 regex `deriveMemoryNote()`，做長輩長期記憶的語意檢索（「阿嬤上次提過膝蓋不舒服」） |

**落地設定**（`cloud/prototype/src/llm/bedrock.js` 現有的 env 開關即可，免改程式）：

```bash
LLM_PROVIDER=bedrock
AWS_REGION=us-west-2
BEDROCK_MODEL_ID=us.anthropic.claude-sonnet-4-6                    # 對話／需求解析
BEDROCK_FAST_MODEL_ID=us.anthropic.claude-haiku-4-5-20251001-v1:0  # 意圖分類
```

現有程式用 `AnthropicBedrock`（`@anthropic-ai/bedrock-sdk`，走 `bedrock-runtime` InvokeModel）——
上面兩個 id 已實測可用，**這條路不必改**。若日後要換 Messages-API 端點，
再改用同一套件的 `AnthropicBedrockMantle`（`new AnthropicBedrockMantle({ awsRegion })`），
屆時 model id 改成不帶區域前綴的 `anthropic.` 形式。

**認證：兩種都實測可用**（`AnthropicBedrock` 兩者皆吃）：

| 方式 | 設定 | 適用 |
|---|---|---|
| **Bedrock API key**（推薦給 server） | `AWS_BEARER_TOKEN_BEDROCK=ABSK...` 單一環境變數 | ✅ 本機開發、App Runner、Render——**不需要 IAM role，也不需要 SigV4 憑證輪替**，部署最單純 |
| SigV4（IAM role / 臨時憑證） | `AWS_ACCESS_KEY_ID` / `SECRET` / `SESSION_TOKEN` | Lambda / ECS 等已有 execution role 的環境，直接繼承 role 權限即可 |

> ⚠️ Bedrock API key 有效期有限（long-term key 可設到期日），**放進 Secrets Manager 並記錄到期時間**，
> 別讓它在 demo 當天無聲過期。走 Lambda 時建議改用 execution role，省掉這個維運風險。

> ⚠️ Bedrock **不支援**這些功能，設計時避開：Web search / Web fetch、Code execution、Files API、
> Batches API、Task budgets、Fast mode。本案都用不到。

### 5.2 SageMaker AI — 兩個真實用途

**用途 A：台語 ASR / TTS 端點（`preferred_lang = 'taigi'` 這條路現在完全靠外部服務）**

- Amazon Transcribe 支援 `zh-TW`（國語），**不支援台語**。
- 現用的 `paulpengtw/faster-whisper-Breeze-ASR-26`（台語優化）→ 部署為 **SageMaker Real-time Endpoint**（`ml.g4dn.xlarge`）。
- 路由邏輯：`elders.preferred_lang == 'mandarin'` → Transcribe；`== 'taigi'` → SageMaker endpoint。
- **成本控制**：GPU endpoint 常開約 $0.736/hr ≈ $530/月。Hackathon 期間用 **EventBridge Scheduler 定時起停**（只在開發與 demo 時段開，8h/天 × 14 天 ≈ $82），或改用 **Asynchronous Inference**（無請求時縮到 0 台）。

**用途 B：跌倒偵測模型的訓練與下發（目前 repo 標註「規劃中，尚未實作」）**

```
資料標註 (SageMaker Ground Truth)
  → 訓練 (SageMaker Training Job, PyTorch)
  → 評估 / 版本管理 (SageMaker Model Registry)
  → 量化與編譯 (SageMaker Neo → INT8 TFLite)
  → S3 → IoT Jobs（OTA）→ Himax WiseEye2 裝置端推論
```

**這條 pipeline 完整體現隱私邊界**：訓練用的是**授權過的資料集**，推論在裝置本地跑，**運行時影像永不進雲**。這是簡報上最好講的一頁。

### 5.3 Kiro — spec-driven 開發

本 repo 已使用 Spectra 做 SDD（`openspec/specs`、`openspec/changes`），與 Kiro 的 spec / steering / hooks 概念直接對應：

| Kiro 概念 | 對應本 repo |
|---|---|
| `requirements.md`（EARS 格式需求） | `docs/requirements/*.md` |
| `design.md` | `docs/architecture.md`＋本文件 |
| `tasks.md` | `openspec/changes/<change>/tasks.md` |
| Steering files | `CLAUDE.md`（四條不可違反的架構約束） |
| Agent Hooks | 「改動 `MockBackend` 狀態機必須跑 `apps/packages/core` 的 flutter test」→ 可做成 on-save hook |

**建議在 hackathon 用 Kiro 做的事**：把 §7 Track B（`AwsBackend` 的 Dart 實作 + AppSync schema + CDK stack）交給 Kiro 的 spec 模式產碼——這是三份高度重複、規格明確的樣板程式，最適合 spec-driven 生成，也讓「有用 Kiro」變成可展示的事實而不是口號。

### 5.4 Excel 匯出（架構約束 4，政府硬需求）

| 資料量 | 方案 |
|---|---|
| 小（單月、單區） | Lambda（`exceljs`）直接查 Aurora → 產 xlsx → 寫 S3 → 回傳 presigned URL |
| 大（全縣市、年度申報） | Aurora → **DMS/排程匯出到 S3（Parquet）** → **Athena** 查 → **Step Functions** 組表 → S3 |

兩個方案都必須把匯出檔放進**加 KMS 加密、有 lifecycle policy** 的 S3 bucket；內含長輩姓名、地址、電話，屬個資。

---

## 6. 安全與合規（服務對象是獨居長者，這段不能省）

| 面向 | 做法 |
|---|---|
| 裝置身分 | IoT Core **X.509 per-device 憑證**；IoT Policy 用 `${iot:Connection.Thing.ThingName}` 變數限縮，讓裝置**只能**訂閱／發布自己的 topic。取代目前公共 broker「任何人都能 publish `jinsun/#`」的狀態 |
| 裝置配網 | Fleet Provisioning by Claiming：家屬 App 走 BLE 傳 Wi-Fi，裝置持 claim 憑證換正式憑證，pre-provisioning hook Lambda 同步寫入 `elders.device_serial` |
| 傳輸加密 | 全鏈路 TLS 1.2+（IoT MQTT 8883、API Gateway HTTPS、Aurora `require SSL`） |
| 靜態加密 | Aurora / DynamoDB / S3 全開 KMS CMK；`radio_events.transcript` 與 `task_messages.text` 含個人對話內容 |
| 金鑰管理 | 現有 `SUPABASE_SERVICE_KEY`、`XCC_GATEWAY_PAT`、`FCM_PRIVATE_KEY` → **Secrets Manager**，Lambda 用 IAM role 取，不再進環境變數 |
| 角色權限 | Cognito 三個 Group（family / volunteer / social_worker）；家屬只看得到 `family_bindings` 綁定的長輩；志工只看得到指派給自己或已廣播的派遣單 |
| 稽核 | CloudTrail（全區）＋ Step Functions 執行歷史（每一次升級的完整時間戳，正好是政府稽核要的證據鏈） |
| 隱私邊界（約束 1） | **在 IAM 層強制**：裝置憑證的 IoT Policy 不授予任何 S3/媒體上傳權限；上雲的只有 `POST /voice` 的文字與主動觸發的語音片段 |
| 資料保存 | 語音暫存檔進 S3 後設 **1 天 lifecycle 自動刪除**；ASR 完成即刪 |

---

## 7. 落地計畫（分 Track，可平行）

### Track A — 事件與 AI 鏈路上 AWS（優先，1–2 天）

| # | 工作 | 產出 | 驗收 |
|---|---|---|---|
| A1 | ✅ **Bedrock 開通已驗證** → 切 provider（設 §5.1 那四個 env） | `LLM_PROVIDER=bedrock` 走通 | `curl /health` 回 `llm.provider=bedrock`；`/voice` 意圖分類正確；語氣不出現「阿公／阿嬤」 |
| A2 | ✅ **IoT Core 已建好並驗證**（§11.2）→ 剩「燒進韌體」 | 韌體 `mqtt_server` 改 `a2zyk2buv4tih2-ats.iot.us-west-2.amazonaws.com`、`setRootCA` 換 Amazon Root CA 1、燒入 device 憑證 | 真板子收得到 `speak`（假裝置端已驗證通過） |
| A3 | ✅ **`POST /voice` → API Gateway + Lambda 已完成並實測**（§11.4） | `jinsun-voice` Lambda + HTTP API + DynamoDB session 表 | ✅ 契約 7 項全過；韌體只需把 `BASE_URL` 換成 `https://yr0ep335el.execute-api.us-west-2.amazonaws.com` |
| A4 | ✅ **Emergency 階梯 → Step Functions 已完成並實測**（§11.3） | `JinsunEmergencyLadder` + `jinsun-speak` Lambda | ✅ 升級準時落在 T0+20.0s；說「我沒事」→ `StopExecution` 中止成功 |
| A5 | Transcribe（國語）接上；SageMaker 台語 endpoint 起一台 | ASR 路由 Lambda | `preferred_lang` 兩種都念得出來 |
| A6 | ~~App Runner 保底部署~~ → **此帳號 SCP 擋死，改以 Render 那台為保底**（§4.3 註記） | 備援 URL（Render，已在線） | 韌體 `BACKEND_AWS` 改回 `0` 即切回 |

**Track A 完成後，「感知 → 決策 → 行動」已經全在 AWS 上**，資料層暫時仍指向 Supabase（`dispatch.js` / `progress.js` 只需改連線字串即可切換）。

### Track B — 資料層與三端（加分，2–3 天）

| # | 工作 | 產出 |
|---|---|---|
| B1 | Aurora Serverless v2 建庫，跑 `schema.sql` | PostgreSQL 實例 + seed 資料 |
| B2 | Cognito User Pool + 三個 Group | 對應 `profiles.role` |
| B3 | AppSync GraphQL schema + Subscription（`radio_events`、`dispatch_tasks`、`task_messages`） | schema.graphql + resolver |
| B4 | Dart：`apps/packages/core` 新增 `AwsBackend implements BackendClient` | 與 `SupabaseBackend` 並存，用 flag 切換 |
| B5 | SNS Mobile Push（APNs + FCM Platform Application） | 取代 `send-push` Edge Function |
| B6 | 社工後台 → S3 + CloudFront | Excel 匯出 Lambda |

> **B4 的關鍵前提**：`apps/packages/core/lib/src/backend_client.dart` 已經是介面抽象（`abstract class BackendClient`，`MockBackend` / `SupabaseBackend` 兩個實作並存），所以第三個實作是**新增**而不是改寫。改動 `MockBackend` 狀態機仍必須跑 `apps/packages/core` 的 `flutter test`（黃金時間合約）。

### Track C — 加分項（時間有餘再做）

- SageMaker 跌倒模型 pipeline（訓練 → Neo 量化 → IoT Jobs OTA）
- Bedrock Knowledge Bases 做長輩長期記憶
- Bedrock Guardrails 上線
- Athena + QuickSight：社工後台的統計儀表板

---

## 8. 部署方式建議

### 8.1 IaC：**AWS CDK (TypeScript)**

| 選項 | 評估 |
|---|---|
| **CDK (TypeScript)** | ✅ **推薦**。與 `cloud/prototype` 的 Node 生態一致；IoT Core、Step Functions、AppSync 的 L2 construct 成熟；Kiro 產 CDK 程式碼的效果好 |
| SAM / CloudFormation | 純 Lambda 專案可行，但 IoT Policy + AppSync resolver 用 YAML 寫會很痛苦 |
| Terraform | 團隊無既有 Terraform 資產，hackathon 期間學習成本不划算 |

**目錄放置**（依 repo 放置規則，雲端相關進 `cloud/`）：

```
cloud/
├── prototype/          現有 Node server（保留，作 App Runner 保底與本機開發）
├── infra/              ← 新增：CDK app
│   ├── bin/jinsun.ts
│   └── lib/
│       ├── iot-stack.ts        IoT Core Thing Type / Policy / Fleet Provisioning
│       ├── api-stack.ts        API Gateway + Lambda（/voice、/whisper）
│       ├── emergency-stack.ts  Step Functions 逾時階梯
│       ├── data-stack.ts       Aurora Serverless v2 + DynamoDB + Cognito
│       ├── fanout-stack.ts     EventBridge + SNS Mobile Push + AppSync
│       └── web-stack.ts        S3 + CloudFront（社工後台）
└── supabase/           現有（Track B 完成後標記為 legacy）
```

### 8.2 CI/CD：GitHub Actions + OIDC（免長期金鑰）

```
push to main
  ├─ flutter analyze + flutter test（apps/packages/core 黃金時間合約）
  ├─ node --test（cloud/prototype）
  ├─ cdk diff → 貼回 PR
  └─ cdk deploy（OIDC assume role，不放 AK/SK）
```

### 8.3 環境策略

Hackathon 期間**只開一個 `dev` 環境**（主辦提供的帳號通常單一）。用 CDK context 區分 stack 名稱前綴，保留日後拆 `prod` 的能力，但不要在賽期花時間做多帳號 Organization。

### 8.4 部署順序（相依關係）

```
1. data-stack      (Aurora / DynamoDB / Cognito — 其他 stack 要 export 出來的 ARN)
2. iot-stack       (IoT endpoint — Lambda 要用)
3. api-stack       (Lambda + API Gateway)
4. emergency-stack (Step Functions — 要 api-stack 的 Lambda ARN)
5. fanout-stack    (EventBridge / SNS / AppSync)
6. web-stack       (S3 + CloudFront)
```

---

## 9. 成本估算（Demo 規模：10 台裝置、20 位使用者）

| 服務 | 用量假設 | 月成本（USD） |
|---|---|---|
| IoT Core | 10 裝置常連 + 5 萬則訊息 | < $1 |
| API Gateway HTTP API | 10 萬次請求 | ~$0.10 |
| Lambda | 20 萬次 × 512MB × 500ms | 免費額度內 |
| Step Functions (Standard) | 3000 次事件 × 8 transitions | ~$0.60 |
| **Bedrock** | Haiku 4.5 意圖分類 + Sonnet 4.6 對話，約 5M in / 1M out | **$20–45** |
| **SageMaker（台語 ASR）** | `ml.g4dn.xlarge`，定時起停 8h/天 | **$60–90**（常開則 ~$530） |
| Transcribe（國語） | 500 分鐘 | ~$12 |
| Polly | 20 萬字元 | ~$3 |
| Aurora Serverless v2 | 0.5–2 ACU，開 scale-to-zero | $20–45 |
| DynamoDB | On-demand，低流量 | < $2 |
| AppSync | 50 萬次 query + 訂閱 | ~$3 |
| Cognito | 20 MAU | 免費 |
| SNS Mobile Push | 1 萬則 | 免費額度內 |
| S3 + CloudFront | < 5GB | < $2 |
| **合計** | | **≈ $130–220 / 月** |

**成本控制三招（賽期必做）**：
1. **SageMaker endpoint 定時起停** — 這是最大單一支出，用 EventBridge Scheduler 只在 09:00–18:00 開。
2. **意圖分類用 Haiku 4.5，只有陪伴對話才用 Sonnet 4.6** — 現有 `llm()` 的 `fast` 參數已經做好這個分流，確認 Bedrock 路徑也套用。
3. **Aurora Serverless v2 設 min 0 ACU** — 夜間無流量時歸零。

另設 **AWS Budgets 告警**（$100 / $200 兩道），避免忘了關 GPU endpoint。

---

## 10. 風險與備援

| 風險 | 影響 | 緩解 |
|---|---|---|
| ~~主辦帳號未開通 Bedrock Claude 模型~~ **（已部分發生）** | 最強模型不可用 | ✅ 已實測：Opus 5 / Sonnet 5 / Opus 4.8 全部 `AccessDenied`，**改用 Sonnet 4.6 + Haiku 4.5**（已驗證品質與延遲可接受）。`llm/bedrock.js` 的三段 fallback（bedrock → mock）仍保留為最後防線 |
| SageMaker GPU 配額不足 | 台語 ASR 不可用 | 降級為 Transcribe `zh-TW`（國語）＋ 韌體端 TTS；`preferred_lang` 欄位保留不動 |
| AppSync 訂閱改造來不及 | 三端不即時 | Track A 已獨立可 demo；資料層維持 Supabase，簡報誠實標示「資料層遷移為下一階段」 |
| IoT Core 憑證燒錄失敗（板子無 RTC、Let's Encrypt 90 天短效憑證的既有雷） | 下行不通 | ✅ 已驗證：AWS IoT 用 **Amazon Root CA 1（長效）**，比現在的 Let's Encrypt 情況**明顯更好**，重燒韌體不必再同步更新時鐘到當天；但仍需設一個合理的開機時間 |
| **topic 或 client id 打錯** | 症狀偽裝成「連線不穩」，極難除錯 | ✅ 已實測：IoT Core 對授權失敗是**切斷連線**而非回錯誤碼（§11.2）。除錯 SOP：反覆斷線先查 topic 字串與 client id↔憑證是否匹配，再查網路 |
| Demo 當天主線異常 | 現場開天窗 | ~~App Runner 保底~~（此帳號 SCP 擋死）→ **Render 那台仍在線當保底**，韌體 `#define BACKEND_AWS` 改回 `0` 重燒即切回（§4.3 註記）。⚠️ 切回去等於換一套資料庫，家屬 App 也要一起切 |

---

## 11. 進場檢查清單（拿到 AWS 帳號的前 30 分鐘）

> ✅ 本清單已於 2026-08-01 對主辦帳號跑過一輪，結果見 §11.1。換帳號／換區域時重跑。

```bash
# 1. 確認身分與區域
aws sts get-caller-identity
echo $AWS_REGION

# 2. Bedrock —— ⚠️ list 出來 ≠ 有權呼叫，一定要「試打」才算數
aws bedrock list-foundation-models --query 'modelSummaries[?providerName==`Anthropic`].modelId'
aws bedrock list-inference-profiles \
  --query 'inferenceProfileSummaries[?contains(inferenceProfileId,`anthropic`)].inferenceProfileId'

# 2b. 真正的權限探測（唯一可信的方法）
for M in us.anthropic.claude-opus-5 us.anthropic.claude-sonnet-5 us.anthropic.claude-opus-4-8 \
         us.anthropic.claude-sonnet-4-6 us.anthropic.claude-haiku-4-5-20251001-v1:0 ; do
  aws bedrock-runtime invoke-model --model-id "$M" --cli-binary-format raw-in-base64-out \
    --body '{"anthropic_version":"bedrock-2023-05-31","max_tokens":8,"messages":[{"role":"user","content":"hi"}]}' \
    /dev/null >/dev/null 2>&1 && echo "  ✅ $M" || echo "  ❌ $M"
done

# 3. SageMaker GPU 配額（決定台語 ASR 能不能上）
aws service-quotas list-service-quotas --service-code sagemaker --max-items 100 \
  --query "Quotas[?contains(QuotaName,'g4dn') || contains(QuotaName,'g5')].[QuotaName,Value]" --output table

# 4. IoT Core endpoint（韌體 mqtt_server 要填這個）
aws iot describe-endpoint --endpoint-type iot:Data-ATS

# 5. Aurora Serverless v2 是否可建（部分 workshop 帳號限制 RDS）
aws rds describe-db-engine-versions --engine aurora-postgresql \
  --query 'DBEngineVersions[].EngineVersion' --output text
```

以上結果直接決定 §7 三條 Track 哪些能做、哪些要降級。**先驗證再寫程式。**

### 11.1 實測結果（2026-08-01 · account `012804034919` · `us-west-2`）

| 檢查項 | 結果 | 對計畫的影響 |
|---|---|---|
| 身分 | `arn:aws:sts::012804034919:assumed-role/WSParticipantRole/Participant` | Workshop 參與者角色，建立 IAM role 時可能受限，Track B 前要先試建一個 role |
| **Bedrock 可呼叫模型** | ✅ `us.anthropic.claude-sonnet-4-6`<br>✅ `us.anthropic.claude-haiku-4-5-20251001-v1:0`<br>❌ Opus 5 / Sonnet 5 / Opus 4.8 / Opus 4.7 / Fable 5（`AccessDenied`） | **§5.1 已改寫**。Opus 5 不可用，改用 Sonnet 4.6 |
| ↳ 已排除的可能原因 | 換 **Bedrock API key（`AWS_BEARER_TOKEN_BEDROCK`）**→ 同樣 AccessDenied；換 **us-east-1** → 同樣 AccessDenied | 錯誤訊息為 `is not available for this account`，屬**帳號層級 model entitlement**，非憑證／區域／IAM 問題。唯一解法是請主辦方為 account `012804034919` 開通 model access |
| Bedrock id 形式 | 裸 `anthropic.*` → `ResourceNotFound`；必須帶 `us.` / `global.` 前綴 | `BEDROCK_MODEL_ID` 一定要填 inference profile id |
| Bedrock 實測 | Haiku 正確分類「我想買牛奶跟雞蛋」→ `need`；Sonnet 4.6 對話 2.7–3.2s | ✅ 意圖分流設計成立，延遲遠小於 8s 第一階 |
| **SageMaker GPU 配額** | `ml.g4dn.xlarge` = **2**、`ml.g5.12xlarge` = 1、`ml.g4dn.4xlarge` = 1 | ✅ 台語 Breeze-ASR endpoint 配額足夠（§5.2 用的就是 g4dn.xlarge） |
| IoT Core endpoint | `a2zyk2buv4tih2-ats.iot.us-west-2.amazonaws.com` | 韌體 `mqtt_server` 直接填此值（取代 mqttgo.io） |
| Aurora PostgreSQL | 11.x–14.x 可用；清單未見 15/16 | ⚠️ 建 Serverless v2 前要確認版本；`schema.sql` 語法在 14 應無問題，但要實跑一次 |

**區域是 `us-west-2`**（非原假設的 APAC）。台灣到 us-west-2 約 130–180ms RTT——
對 20 秒黃金窗無影響，但下行 TTS 播報會有可感延遲，demo 時值得先說明。

### 11.2 IoT Core 下行鏈路實測（2026-08-01，已建實體資源）

已在帳號內建立並跑完端對端驗證：

| 資源 | 值 |
|---|---|
| Thing | `JS-REAL-0001`（`arn:aws:iot:us-west-2:012804034919:thing/JS-REAL-0001`） |
| 憑證 | `arn:aws:iot:us-west-2:012804034919:cert/9360515f2ebf…15bf2`（ACTIVE，已綁 thing） |
| Policy | `JinsunDevicePolicy`（內容即 §附錄 B） |
| Endpoint | `a2zyk2buv4tih2-ats.iot.us-west-2.amazonaws.com` |
| Root CA | Amazon Root CA 1（**長效**，取代目前 Let's Encrypt 90 天短效憑證的維運負擔） |

**驗證結果**（用 `mqtt` 套件持憑證扮演裝置，server 端以 `aws iot-data publish` 下發）：

| 項目 | 結果 |
|---|---|
| TLS 8883 + X.509 連線 | ✅ |
| 訂閱 `jinsun/JS-REAL-0001/cmd`（QoS 1） | ✅ 授予 qos=1 |
| server → IoT Core → 裝置 | ✅ payload 與現有契約**一字不差**（`{"commands":[{"type":"speak",…},{"type":"device",…}]}`） |
| **投遞延遲** | **14ms**（IoT Core 內部；不含台灣↔us-west-2 的 RTT） |
| **`cleanSession=false` 離線補投** | ✅ 斷線期間 publish 的 QoS 1 訊息，重連後 `sessionPresent=true` 並確實補投——**與 mqttgo.io 同等，契約要求成立** |
| QoS 1 at-least-once | ✅ 未正確 PUBACK 就斷線 → IoT Core 重送（韌體務必正確回 PUBACK，否則會收到重複指令） |

**⚠️ 對韌體最重要的一個發現：IoT Core 的授權失敗處理方式是「直接切斷連線」，不是回 SUBACK `qos=128`。**

| 越權行為 | IoT Core 反應 |
|---|---|
| 用別台裝置的 client id 連線（憑證不符） | 連線無回應／被拒 |
| 訂閱別台裝置的 `cmd` topic | **整條連線被切斷** |
| publish 到別台裝置的 topic | **整條連線被切斷** |

含意：**topic 打錯一個字，症狀會長得像「連線不穩」而不是「權限錯誤」**。
韌體既有的指數退避重連（1s→2s→…→30s）因此從「nice to have」變成**必要**；
除錯時若看到反覆斷線，第一個要懷疑的是 topic 字串或 client id 與憑證不匹配，而不是網路。

> 🔑 **憑證檔案存放**：私鑰目前只在本 session 的暫存目錄，**session 結束即消失**。
> 要燒進韌體的話請先複製出來妥善保管（**切勿進 git**），或用 `aws iot create-keys-and-certificate` 重簽一組。
>
### 11.3 Emergency 逾時階梯實測（2026-08-01，Track A4 已完成）

已建立並跑通：

| 資源 | 值 |
|---|---|
| Lambda | `jinsun-speak`（`nodejs22.x`，bundle `@aws-sdk/client-iot-data-plane`，2.4MB） |
| Lambda role | `JinsunSpeakLambdaRole`（`iot:Publish` 限縮 `jinsun/*`） |
| 狀態機 | `JinsunEmergencyLadder`（STANDARD） |
| SFN role | `JinsunEmergencyLadderRole`（`lambda:InvokeFunction` 限縮 `jinsun-*`） |

**實測時序**（`get-execution-history`，相對 execution 開始）：

```
T+ 0.00s  ExecutionStarted
T+ 0.02s  Wait（→ step1At）
T+ 7.05s  SpeakStep1        ← 長輩實際聽到：T0+8.67～9.13s
T+ 7.19s  Wait（→ escalateAt）
T+19.24s  Escalate          ← 換算回 T0 正好 20.0s ✅ 守住黃金窗
T+19.24s  SpeakOnEscalated  ← 長輩實際聽到：T0+20.41～20.94s
T+19.41s  ExecutionSucceeded
```

> **「20 秒」量的是升級動作本身，不是長輩聽到安撫語的時刻。**
> `Escalate`（寫 `dispatch_tasks` → 三端推播）準時落在 T0+20.0s；
> 安撫語再晚 0.4–0.9s 才到收音機（Lambda invoke + IoT publish + MQTT 傳遞）。契約要求的是前者。

| 驗收項 | 結果 |
|---|---|
| 兩輪連續測試的升級落點 | 20.41s / 20.94s（含傳遞）— **偏差不累積** |
| 相對 Wait（改版前） | ❌ 21.55s，超窗 1.55s —— 這就是改用絕對時間戳的原因 |
| 解除（`StopExecution`） | ✅ execution → `ABORTED`，後續 25 秒收音機**零指令** |
| payload 契約 | ✅ 與 `hardware-integration.md` §② 一字不差 |

**尚未接上**：`Escalate` 目前是 `Pass` 佔位（回傳固定 `etaMinutes: 8`）。
接資料層時換成 Lambda 寫 `radio_events` / `dispatch_tasks`，狀態機結構不用改。
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

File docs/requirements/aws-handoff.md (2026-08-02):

# AWS 平行環境 · 交接文件

> 撰寫於 2026-08-01，同日更新（補上三端 App 那半邊）。
> 接手前請先讀完「§1 立刻要處理」——有三件事有時效性。
>
> 設計理由與完整實測數據見 [`aws-architecture.md`](aws-architecture.md)；
> 目錄結構與部署指令見 [`../../cloud/aws/README.md`](../../cloud/aws/README.md)。

## 0. 一句話現況

**伺服器端的平行環境已完整可跑**（語音 → 意圖分類 → 20 秒升級 → 派遣 → 收音機播報 → 進度回報），
資料庫是自己的 Aurora、**與正式環境 Supabase 完全斷開**。

**三端 App 那半邊也已完成並部署**（Cognito 認證、`jinsun-data` 資料 API、`aws_backend.dart`、
建置切換旗標、S3 + CloudFront 三端站台），且已在真 AWS 上跑過完整黃金鏈路：

```
疑似跌倒 → 家屬端 3 秒內看到「確認中」→ 20 秒升級（實測 T0+24s，含 2s 輪詢誤差）
→ 開派遣單並就近派給志工 → 志工接單（重複接單回 409）→ 家屬↔志工聊天
→ 到場 → presigned S3 上傳結案照片 → 結案 → 時間銀行 +21 分 → 長輩燈號回綠、事件 closed
```

解除路徑（長輩回「我沒事」）亦已驗：Step Functions execution 轉 `ABORTED`，不會誤升級。

程式碼在本 repo 分支 `feat/aws-parallel-environment`，**尚未 push 到遠端**。
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

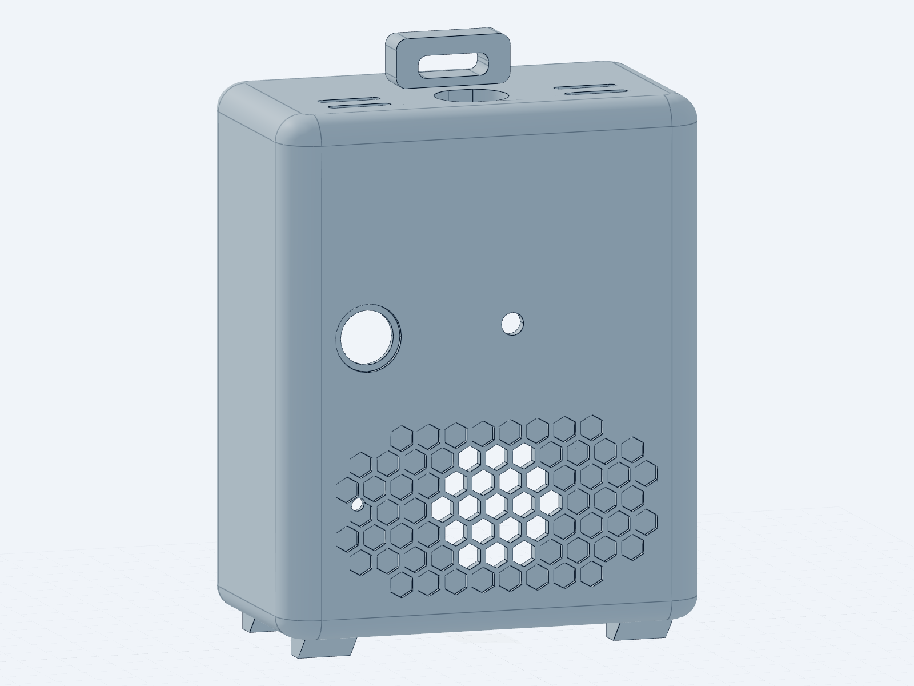
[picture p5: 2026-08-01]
hardware/enclosure/snapshots/shell_round_v2_20260722T141316Z.png

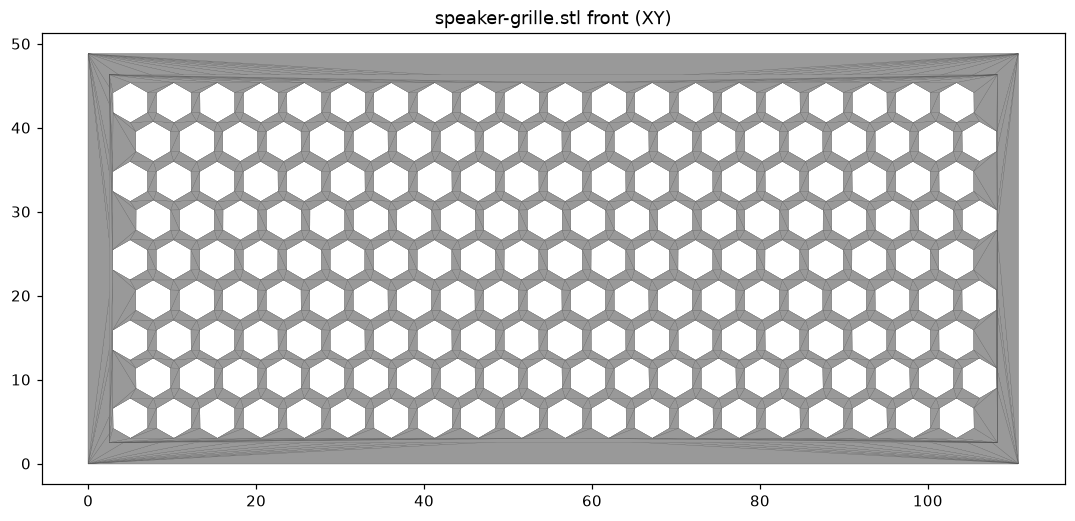
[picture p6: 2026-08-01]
hardware/enclosure/snapshots/grille_ref_front.png

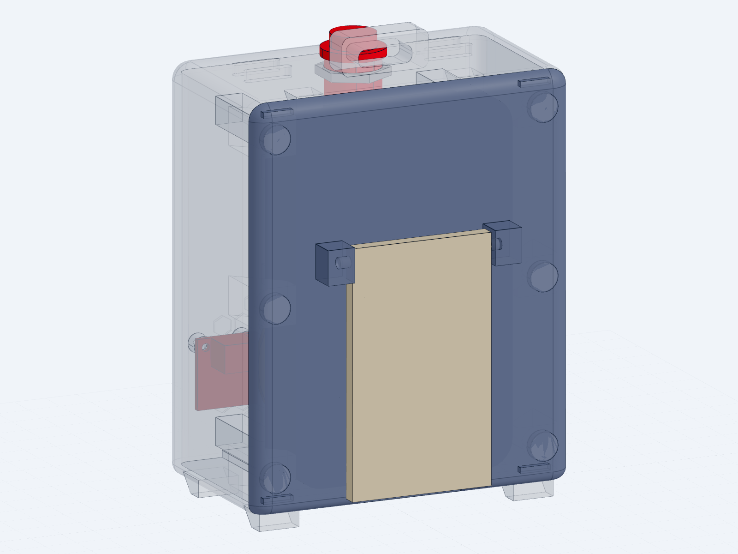
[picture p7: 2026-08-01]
hardware/enclosure/snapshots/asm_flap_back_20260722T135902Z.png

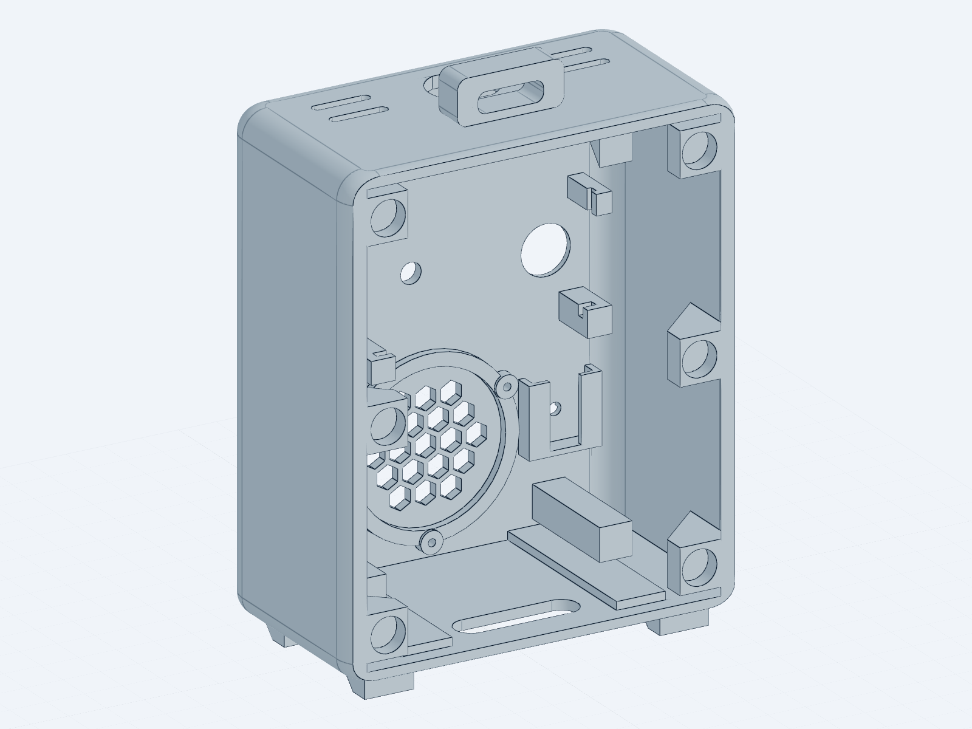
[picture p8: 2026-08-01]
hardware/enclosure/snapshots/shell_final_interior_20260722T143218Z.png

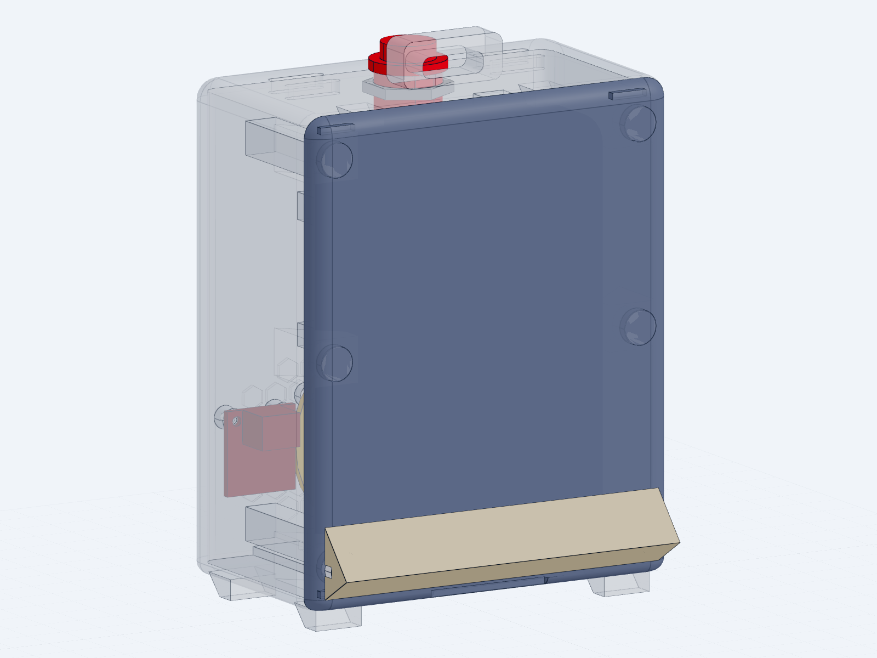
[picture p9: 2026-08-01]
hardware/enclosure/snapshots/asm_back_stand_20260722T135325Z.png

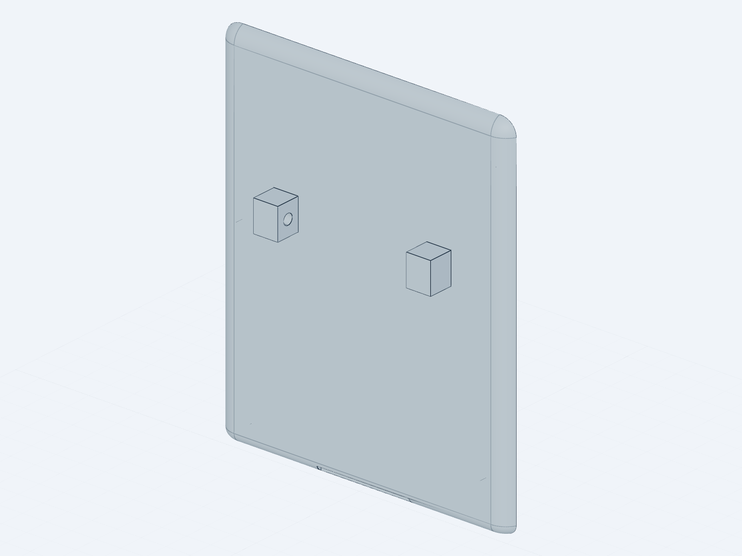
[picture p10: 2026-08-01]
hardware/enclosure/snapshots/panel_hinge_20260722T135907Z.png

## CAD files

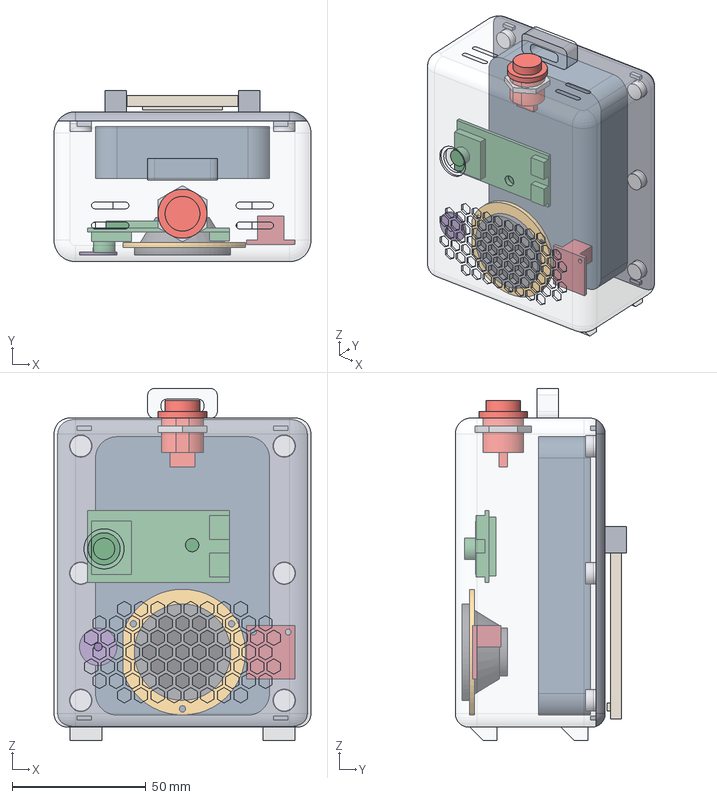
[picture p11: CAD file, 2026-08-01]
hardware/enclosure/hub8735_speaker_assembly.step
96.0 x 64.0 x 131.5 mm
back_panel_magnetic
hub8735_ultra_board
speaker_36mm_3w_4ohm
speaker_clamp_ring
inmp441_mic_module
max98357a_amp_module
powerbank_md_bp075qi
pushbutton_16mm_r13
pushbutton_nut_m16
stand_flap_folded
magnet_shell_right_0
magnet_panel_right_0
magnet_shell_left_0
magnet_panel_left_0
magnet_shell_right_1
magnet_panel_right_1
magnet_shell_left_1
magnet_panel_left_1
magnet_shell_right_2
magnet_panel_right_2
magnet_shell_left_2
magnet_panel_left_2

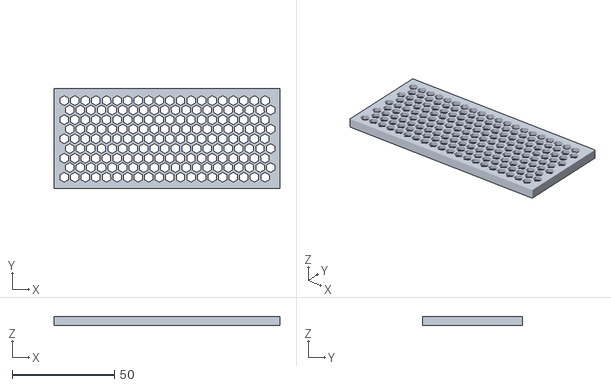
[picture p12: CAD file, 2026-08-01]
hardware/enclosure/reference/speaker-grille.stl
110.8 x 48.8 x 4.50

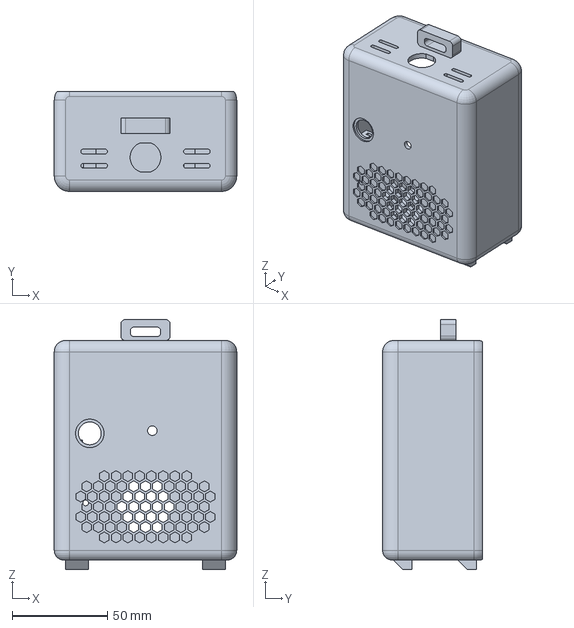
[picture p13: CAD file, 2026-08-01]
hardware/enclosure/shell_print.step
96.0 x 52.5 x 131.5 mm

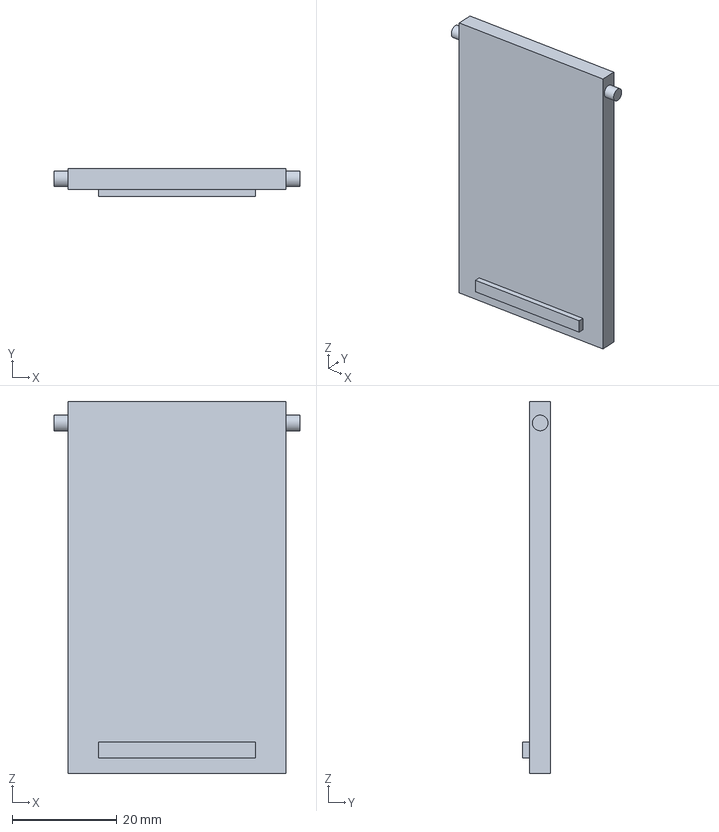
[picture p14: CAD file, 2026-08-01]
hardware/enclosure/stand_flap_print.step
47.0 x 5.40 x 71.1 mm

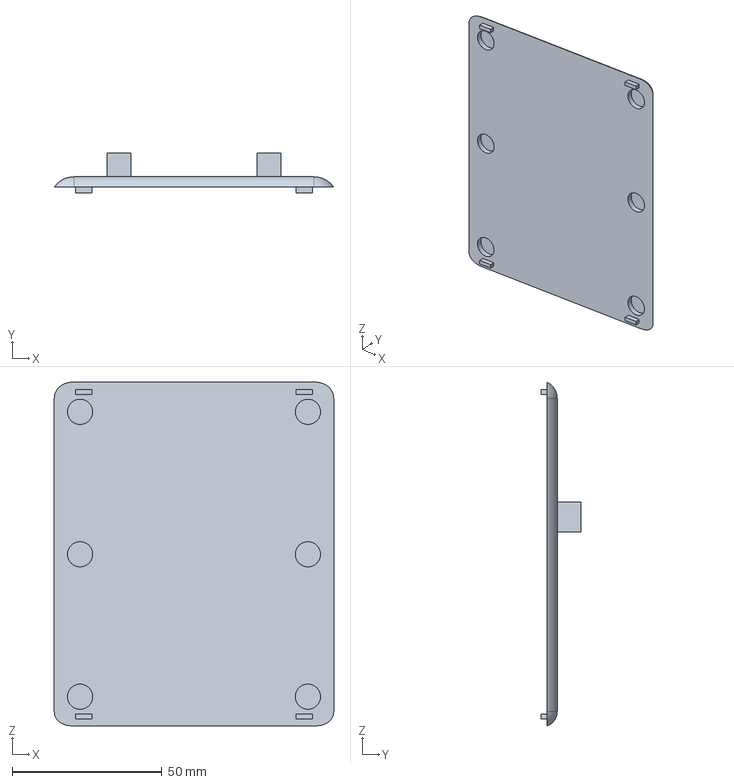
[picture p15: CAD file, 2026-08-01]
hardware/enclosure/back_panel_print.step
93.2 x 13.5 x 114.7 mm

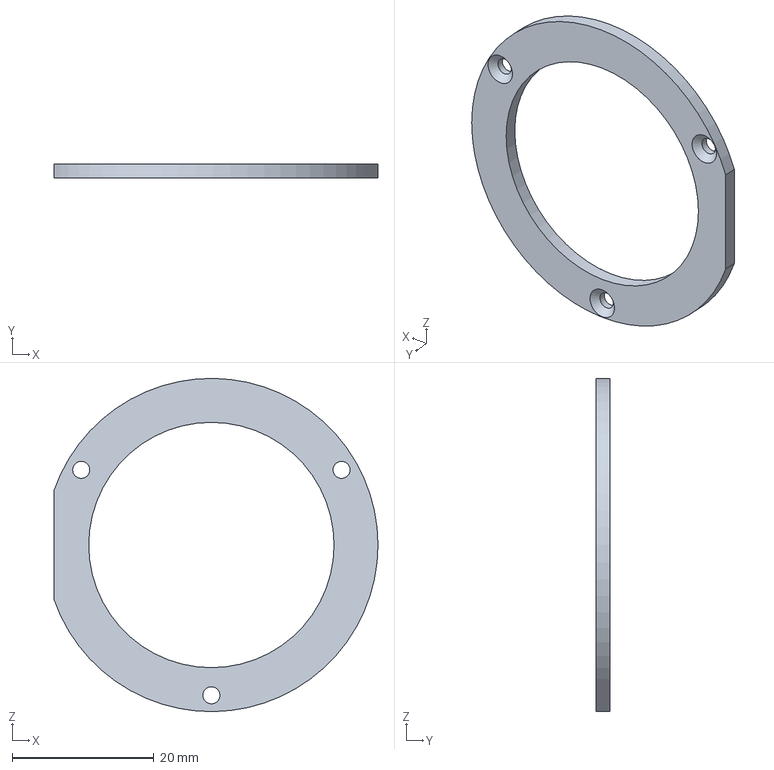
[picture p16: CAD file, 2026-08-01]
hardware/enclosure/speaker_clamp_print.step
45.7 x 2.00 x 47.0 mm

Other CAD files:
hardware/enclosure/print/back_panel_print.3mf
hardware/enclosure/print/back_panel_print.stl
hardware/enclosure/print/shell_print.3mf
hardware/enclosure/print/shell_print.stl
hardware/enclosure/print/speaker_clamp_print.3mf
hardware/enclosure/print/speaker_clamp_print.stl
hardware/enclosure/print/stand_flap_print.3mf
hardware/enclosure/print/stand_flap_print.stl

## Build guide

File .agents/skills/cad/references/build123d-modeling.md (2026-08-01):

# build123d modeling patterns

Read this file when writing or repairing build123d Python source.

## Modeling objective

Create a valid STEP-ready BREP model, not a visual mesh. Prefer closed solids, explicit labels, and stable parametric dimensions. Define `gen_step()` returning the STEP-ready shape or labeled compound; the CLI owns output paths (see `step-generation.md`).

## Design strategy

Decide how the part is constructed before writing geometry code:

- **Choose the construction that makes the spec's dimensions direct parameters.** Profile-driven shapes get one closed sketch plus `extrude`/`revolve`/`sweep`/`loft`; block-and-feature parts get a base solid plus subtractive features. Prefer whichever construction lets the user's controlling dimensions appear as named parameters instead of derived values.
- **Decide part vs assembly before modeling.** Bodies that are separately manufactured, purchased, or movable belong in a labeled assembly (see `positioning.md`); monolithic manufacturing intent gets a single fused solid. Avoid unlabeled compounds of solids — multi-body output without occurrence labels loses traceability in inspection and viewer review.
- **Pick the origin and orientation from the functional datum before sculpting.** Model on the mating interface, mounting plane, or symmetry axis; see `positioning.md` for part-type origin defaults.
- **Order operations so fragile steps come last and failures localize.** Base solid → major additions → subtractive features → shell → through-wall holes → fillets and chamfers last. Fillets are the most failure-prone operation and every boolean invalidates selectors, so postpone them. Structure the source so each feature is a named step — a per-feature function or a distinct intermediate variable — so a failed operation points at exactly one feature and a parameter change touches one obvious place.
- **Overshoot boolean tools.** Extend cutting tools past the faces they enter and exit; for through-cuts, go roughly 1 mm beyond both faces. Coincident or coplanar tool/target faces are a classic kernel failure. Cut repeated or patterned features in one combined operation.
- **Sanity-check proportions before generating.** Compare the expected bounding box against the real-world object, wall thickness against overall size, and feature positions against edges and neighboring features. Order-of-magnitude and collision errors pass geometric validation but fail visual review.

## Topology stack

Think in this order:

```text
Vertex → Edge → Wire → Face → Shell → Solid → Compound
```

For assemblies, use these repo topology terms consistently:

- **Occurrence**: a placed node in the assembly tree. An occurrence has a parent, transform, path, and user-facing role such as `lid` or `m3_screw:front_left`.
- **Shape**: an exported geometry/body inside an occurrence. Shape rows own topology; faces and edges belong to a shape, and the shape belongs to an occurrence.
- **Face/edge**: selectable topology owned by a shape. Do not assume arbitrary faces or edges have persistent intent labels; inspect them by occurrence, shape, ordinal, surface/curve type, and measured geometry.

When inspecting topology, follow `assembly occurrence -> shape/body -> faces -> edges`. Every face/edge row should be traceable through both `occurrenceId` and `shapeId`.

For normal STEP output, return one of:

- a valid `Solid`
- a compound of valid solids
- a labeled assembly compound

Avoid returning loose wires, open faces, or construction surfaces unless the user explicitly requested them.

## Parameters first

Put meaningful dimensions in named variables:

```python
width = 80.0
depth = 50.0
thickness = 6.0
hole_diameter = 4.5
hole_offset_x = 30.0
hole_offset_y = 17.5
```

Avoid burying important numbers inside geometry calls.

## Coordinate system

Declare or comment the convention:

```text
Origin: center of primary part or chosen mating datum
XY: main base/sketch plane
+Z: up/extrusion direction
```

Use `Location`, `Plane`, and `Axis` intentionally. For positioning-sensitive tasks and source-level assembly relationships, read `positioning.md`.

## Builder contexts

Use the context that matches the geometry:

```python
with BuildLine() as path:
    ...

with BuildSketch() as profile:
    ...

with BuildPart() as part:
    ...
```

Typical flow:

```text
curves/paths → sketches/profiles → solids/features → labels → STEP
```

## Selection practices

Avoid fragile topology order when possible. Select by:

- axis or normal
- location or bounding position
- plane grouping
- feature intent
- stable construction plane
- inspected local selector ref for downstream validation

For source operations, prefer robust selectors such as top/bottom by axis or position rather than arbitrary list indexes.

## Assemblies and positioning

For assemblies, keep this file focused on BREP modeling patterns and labels. Use `positioning.md` as the single source of truth for:

- part-local coordinate conventions
- when to use `cadpy.assembly.AssemblyHelper`, build123d joints, or explicit `Location` transforms
- `connect_to()` behavior
- CLI `inspect align` as read-only selector-pair alignment validation
- frame, measure, and positioning report expectations

## Labels and assemblies

Label every exported part and assembly child with native build123d labels. Prefer concise intent labels through `cadpy.assembly` helpers:

```python
from cadpy.assembly import AssemblyHelper, label_shape

asm = AssemblyHelper("electronics_enclosure")
base = asm.add(make_base(), "base")
lid = asm.add(make_lid(), "lid")

boss = label_shape(Cylinder(radius=3.0, height=12.0), "m3_boss", "front_left")
```

Do not prefix labels with topology categories like assembly, component, feature, datum, mate, or hardware. The assembly tree and topology inspection already expose those structural categories. Use labels for the intent topology cannot reliably infer: role, placement, interface, repetition, or mating purpose. Feature labels survive STEP export best when the feature remains a labeled child shape in a `Compound`; boolean-subtracted or fused feature history should be represented by source parameters, named datums, and validation refs instead of assumed persistent feature labels.

Label for inspection:

- Label the root assembly.
- Label every exported part, subassembly/module, and repeated component occurrence.
- Use occurrence labels for assembly role and placement, especially repeated parts: `m3_screw:front_left`, `m3_screw:rear_right`.
- Use shape labels for retained exported geometry/body roles where useful.
- Use feature/datum labels only when that geometry remains exported as a child shape.
- Use named mate datums for source-level positioning intent, then validate the exported STEP topology and occurrence frames.

Occurrence and shape labels are exported through STEP names and surfaced in `STEP_topology` when available. The viewer uses occurrence labels for assembly/tree references and shape labels for shape references. Faces and edges inherit their context from `occurrenceId` and `shapeId`; do not promise persistent face/edge intent labels unless explicit tested support exists.

For repeated parts, keep occurrence labels, transforms, or joint connections explicit and inspect frames/positioning after generation.

## Common failure modes

- Fillet radius larger than local edge geometry.
- Open sketch profile produces invalid or missing face.
- Face selector changes after a boolean or fillet.
- Part origin is arbitrary and later alignment checks become ambiguous.
- Source-level joints are treated as if they were persistent STEP constraints rather than one-time source placement operations.
- Joint labels are missing, duplicated, or attached to the wrong local datum.
- `.connect_to()` fixes the wrong side of the relationship, moving the part intended to remain fixed.

Use `repair-loop.md` when generation or validation fails.

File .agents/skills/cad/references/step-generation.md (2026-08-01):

# STEP generation

Read this file when generating or regenerating STEP/STP artifacts from build123d Python source or from direct STEP/STP targets.

## Tool

The launcher lives in the CAD skill directory:

```bash
python scripts/step [--kind {part|assembly}] targets... [flags]
```

Use explicit target paths only; target paths resolve from the command cwd unless absolute. Do not rely on directory-wide generation.

Plain generated Python targets write sibling `.step` outputs. Use `-o`/`--output` only with one plain generated Python target, or use `SOURCE.py=OUTPUT.step` positional pairs for per-target custom outputs. Paired output paths resolve from the command cwd and are valid only for generated Python sources, not direct STEP/STP inputs. Do not put output paths in the `gen_step()` return value; the CLI owns output paths.

## Generated Python source

This is the default path when designing from scratch or modifying a generated model. Generated build123d sources define:

```python
def gen_step():
    ...
    return step_ready_shape_or_labeled_compound
```

Generated Python targets infer their kind from the source metadata and `gen_step()` return value; pass the source path directly:

```bash
python scripts/step path/to/part.py
python scripts/step path/to/part.py -o path/to/custom.step
python scripts/step path/to/a.py=out/a.step path/to/b.py=out/b.step
python scripts/step path/to/assembly.py
```

Passing a generated assembly `.step` directly treats it as imported native STEP and loses source-level assembly composition; pass the `.py` assembly source. For generated build123d assemblies, prefer `cadpy.assembly.AssemblyHelper` in the Python source so native labels, named mate frames, and source-level relationships are preserved before STEP export (see `positioning.md`).

## Direct STEP/STP imports

Use a direct STEP/STP target when no generator exists (imported or downloaded STEP) or the user explicitly identifies a STEP/STP file as the target. The GLB/topology artifacts are then generated from the STEP file itself:

```bash
python scripts/step --kind part path/to/imported.step
```

Direct targets support the same mesh sidecar flags as generator targets; read `supported-exports.md` for STL and 3MF sidecars.

## Viewer artifacts

Every `scripts/step` run also writes hidden adjacent GLB/topology artifacts as part of the normal build. They power CAD Viewer review, `$cad-viewer` workflows, and `scripts/inspect` refs, and are not optional in the STEP workflow.

## After generation

- Confirm the process succeeded and the STEP file exists and is non-empty.
- Run the baseline inspection and any spec-driven checks per `inspection-and-validation.md`:

```bash
python scripts/inspect refs path/to/model.step --facts --planes --positioning
```

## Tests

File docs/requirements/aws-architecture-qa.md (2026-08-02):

# 架構圖 Q&A · 評審備詢

> 對象：看完 [`docs/assets/aws-architecture.drawio`](../assets/aws-architecture.drawio) 之後的提問。
> 撰寫於 2026-08-02。每題都是「一句話先答完 → 追問才展開」的格式，數字一律取自實測。
> 佐證來源：[`aws-architecture.md`](aws-architecture.md)（設計理由與實測數據）、
> [`aws-handoff.md`](aws-handoff.md)（環境識別碼與踩雷紀錄）、
> [`hardware-integration.md`](hardware-integration.md)（裝置契約）。
>
> **一句話講完整套系統**：長輩家裡一台沒有螢幕的收音機，偵測到疑似跌倒後語音問候，
> 20 秒沒回應就自動升級——推播家屬、開派遣單、就近媒合志工，全程在 AWS 上跑閉環，
> 而**影像永遠不離開那個家**。

---

## 目錄

- [A. 一分鐘看懂這張圖](#a-一分鐘看懂這張圖)
- [B. 架構選型（最常被問）](#b-架構選型最常被問)
- [C. 隱私與資安](#c-隱私與資安)
- [D. AI 的部分](#d-ai-的部分)
- [E. 可靠性與規模](#e-可靠性與規模)
- [F. 圖上細節的追問](#f-圖上細節的追問)
- [G. 誠實面對的缺口](#g-誠實面對的缺口)
- [H. 一頁速查表](#h-一頁速查表)

---

## A. 一分鐘看懂這張圖

圖上有兩條進雲的路，這是理解整張圖的關鍵：

| | 誰在用 | 走哪 | 為什麼分開 |
|---|---|---|---|
| **上行** | 收音機 | HTTPS → API Gateway | 事件與文字，請求／回應，同步拿到要立刻播的那句話 |
| **下行** | 收音機 | IoT Core MQTT → 裝置 | 雲端要「主動」對長輩說話，HTTPS 做不到 |

四端（長輩／家屬／志工／社工）是同一套 Flutter 程式碼，走 CloudFront + S3 靜態站，
資料一律打 `/data/*` 並帶 Cognito 的 JWT。

**黃金鏈路**（整套系統的核心，20 秒）：

```
疑似跌倒 → jinsun-voice 同步回一句「阿春，您還好嗎？」→ 寫 radio_events(attention)
        → Step Functions 開始計時
        ├─ T0+8s   沒回應 → jinsun-speak → IoT Core publish →「我沒有聽到您的聲音…」
        └─ T0+20s  仍沒回應 → 升級：開派遣單、就近派志工、推播家屬、長輩燈號轉紅
長輩若回「我沒事」→ StopExecution，整條升級鏈當場中止
```

---

## B. 架構選型（最常被問）

### Q1. 為什麼 20 秒的計時器要用 Step Functions？程式裡寫個 `setTimeout` 不就好了？

**因為計時器不能活在單一行程的記憶體裡。** 原本的 `emergency.js` 就是 `setTimeout`——
只要那個行程重啟、擴容、被回收，正在等待的那位長輩就永遠等不到升級，而且**不會有任何錯誤訊息**。
這是我們認定的單一最高風險，所以是遷移清單裡的第一項。

追問時可以展開三個實作細節，都是實測踩出來的：

1. **不能用相對 `Wait`。** 用 `Seconds: 8` / `Seconds: 12` 時，每一步的轉場開銷會累積，
   實測升級落在 **21.55 秒、超窗 1.55 秒**。改成絕對時間戳（`TimestampPath`）後，
   各步偏差彼此獨立且有界，穩定落在 **T0+20.11s**。
2. **Step Functions 不能直接發 MQTT。** AWS SDK 整合清單沒有 IoT Data Plane，
   `aws-sdk:iotdata:publish` 會 `SCHEMA_VALIDATION_FAILED`，一律要經 `jinsun-speak` Lambda 代打。
3. **選 Standard 不選 Express**，因為 Standard 保留完整執行歷史——
   每一次升級的完整時間戳，正好就是政府稽核要的證據鏈。成本一天 100 次事件約 $0.02/月。

**解除路徑也驗過**：長輩說「我沒事」→ 用 DynamoDB 存的 `executionArn` 呼叫 `StopExecution`，
execution 轉 `ABORTED`，後續 25 秒收音機零指令。

---

### Q2. 為什麼是 Lambda 而不是一直開著的容器？

**因為這個系統的流量長相是「絕大多數時間沒事，有事的時候要在 20 秒內走完一條多步驟鏈路」。**
常駐容器在 99% 的時間是空轉付費，而 Lambda 的冷啟（實測 `jinsun-tts` 冷啟 329ms、熱 225ms）
相對 20 秒的窗口可以忽略。

補充一個**誠實的背景**：我們原本也準備了容器那條路當保底（`deploy/aws/`），
但實測 App Runner 在主辦帳號被 SCP 擋死（`no service control policy allows apprunner:ListServices`），
後來改寫成 ECS Fargate + ALB，但**那條沒有實跑過**。目前真正在跑的是 Lambda 這條。

---

### Q3. 為什麼資料庫選 Aurora（關聯式），而不是全用 DynamoDB？

**因為業務本身就是關聯式的，而且我們有一份已經在正式環境跑過的 schema。**

長輩 ↔ 家屬綁定 ↔ 派遣單 ↔ 志工 ↔ 聊天訊息 ↔ 時間銀行點數，共 13 張表、彼此都有外鍵。
硬要壓成 DynamoDB 的 single-table design，等於重新設計整個資料模型——
在有限時間內這是高風險低報酬。實際做法是 `transform-schema.mjs` 從
`cloud/supabase/schema.sql` 自動轉出 Aurora 版本（只砍掉 Supabase 專屬的四塊），
**兩套環境共用同一份 schema 定義**。

**DynamoDB 我們也在用**，但只用在它擅長的三件事——都是 key-value 且都設了 TTL：

| 表 | 用途 |
|---|---|
| `jinsun_emergency_sessions` | 誰正在等回應、對應的 Step Functions execution ARN |
| `jinsun_progress_announced` | 播報去重（同一張單不重複念） |
| `jinsun_downlink` | 下行扇出佇列，給瀏覽器版硬體模擬器長輪詢用 |

---

### Q4. Aurora 在 VPC 裡，但 Lambda 不在 VPC，這樣連得到嗎？安全嗎？

**走 RDS Data API**，那是一個 HTTPS 端點，用 IAM 授權，所以 Lambda 不必進 VPC。

這帶來兩個好處：**沒有 VPC 冷啟延遲**（ENI 附掛會讓冷啟多好幾秒，直接吃掉黃金窗），
以及**資料庫沒有對外的網路路徑**——它待在 private subnet，誰都連不進去，
存取一律經過 IAM + Secrets Manager（主密碼由 RDS 託管輪替，無人經手）。

另一個容易被追問的點：**Aurora 的最小容量刻意設 0.5 ACU 而不是 0。**
Serverless v2 從零擴容約 15 秒，那會直接吃掉 20 秒黃金窗。代價是它成為整套環境
**唯一持續計費**的資源（約 $43/月）。這是我們明知成本仍然選的——救命鏈路不能等資料庫醒來。

---

### Q5. 為什麼三端是「輪詢」而不是 AppSync 訂閱？這樣不夠即時吧？

**這題我們準備了，而且第一個理由是決定性的：訂閱對最重要的那條鏈路根本不會響。**

AppSync 的 subscription 只在「經過 AppSync 的 mutation」時觸發。但 20 秒逾時升級、開派遣單，
是 Step Functions 叫 Lambda **直接寫 Aurora**——黃金鏈路刻意不繞路。
要讓訂閱響，就得讓每一支後端 Lambda 寫完資料庫後反手再呼叫一次 AppSync publish，
**多一個相依、多一個失敗點，而那個失敗點正好落在系統最不能失敗的地方。**

第二，這個系統的即時性標準是 20 秒，不是 200 毫秒。而且做法不是笨輪詢：

- `GET /data/version` 回六張表的**變更指紋**，App 每 3 秒打一次，指紋沒變就不抓快照。
- 指紋不是 `count(*)` + `max(時間)`——事件從 `open` 翻成 `escalated`、燈號從黃翻紅，
  這兩件事都不新增列也不動時間欄位，卻正是最需要立刻反映的變化，所以指紋涵蓋「會影響畫面的欄位」本身。
- **使用者自己的動作永遠是即時的**：每次寫入後立刻強制抓一次快照。3 秒只發生在「別人動的」。

第三個理由是誠實的：交接當下 AWS 憑證已過期，AppSync 無法實際部署驗證，
**一套沒跑過的訂閱鏈路不該進 demo。**

要升級成真訂閱時**介面完全不必動**——`AwsBackend` 對外仍是那 8 個 `Stream`，
只要把 `_tick()` 換成訂閱回呼。

---

### Q6. 這張圖的單點故障在哪裡？

誠實列給評審看，比被問出來好：

| 元件 | 掛掉的後果 | 現況 |
|---|---|---|
| **Aurora** | 派遣、快照全停；語音對話仍可回應 | 單一 cluster，無跨區。Demo 規模的取捨 |
| **IoT Core** | 雲端無法主動對長輩說話（上行仍通） | 區域級服務，AWS 託管 |
| **Bedrock** | 對話降級 | `llm/bedrock.js` 有三段 fallback（bedrock → mock），不會整條斷 |
| **API Gateway** | 上行全斷 | 唯一入口，是真正的單點 |
| **SageMaker ASR endpoint** | 長輩講話沒人聽得懂 | 單一 endpoint。韌體裡保留 XCC Gateway 為註解掉的備援，換兩行重燒即切回 |
| 台語 TTS（ATEN） | 台語念不出來 | **非 AWS**，且 Polly 無閩南語音色，目前無等價替代 |

Demo 當天的保底：Render 那套環境仍在線，韌體開頭 `#define BACKEND_AWS 0` 重燒即切回。
⚠️ 但切回去等於換一套資料庫，家屬 App 也要一起切。

---

## C. 隱私與資安

### Q7. 相機會拍到長輩，影像會傳到雲端嗎？

**不會，而且這是我們寫死在架構約束裡的第一條：影像永遠不離開那個家。**

跌倒推論在裝置端的 Himax WiseEye2 上做，**跨越裝置與雲端那條線的只有「事件」與「文字」**。
唯一會上雲的音訊，是長輩**主動觸發**的那一段（按住按鈕、或本地 NPU 聽到求救聲），
上傳做 ASR、轉成文字之後就結束——`POST /voice` 的契約**只收文字，不收音檔**。

追問「怎麼保證不是嘴上說說」時，答**在 IAM 層強制**：
裝置憑證的 IoT Policy 不授予任何 S3 或媒體上傳權限，裝置在技術上就沒有把影像送上去的能力。

還有一個設計細節值得講，它顯示我們對「誤報」的態度：
本地音訊分類聽到**撞擊聲絕不單獨上報**，只開一扇 3 秒佐證窗，
窗內再聽到求救聲才判定跌倒。寧可漏，不要天天誤報把長輩的信任耗光。

---

### Q8. 裝置怎麼認證？會不會有人冒充收音機發假的求救訊號？

**IoT Core 用 per-device 的 X.509 雙向 TLS**，而且 policy 用 `${iot:Connection.Thing.ThingName}`
變數限縮，每台裝置**只能**訂閱與發布自己的 topic：

```json
"iot:Subscribe" → "topicfilter/jinsun/${iot:Connection.Thing.ThingName}/cmd"
"iot:Publish"   → "topic/jinsun/${iot:Connection.Thing.ThingName}/status"
```

這一步同時解掉了正式環境的一個真實資安洞：那邊用的是公共 MQTT broker（`mqttgo.io`），
**無認證，任何人都能 publish `jinsun/#`**——也就是任何人都能叫任何一台收音機說任何話。
搬上 IoT Core 是這次遷移在資安上最實質的改善。

（一個除錯 SOP 值得順帶講，顯示我們真的踩過：IoT Core 對授權失敗是**直接切斷連線**、
不回 SUBACK 128，所以 topic 打錯一個字，症狀會長得像「網路不穩」。）

---

### Q9. Supabase 的 RLS 拿掉之後，越權怎麼防？

**改寫成 `cloud/aws/lambda/data/authz.mjs`，分讀寫兩層，而且比原本嚴格。**

坦白講，原環境的 RLS 其實是 demo 全開（`for select using (true)`），不能照搬也不值得照搬。

- **讀**：角色 → SQL 述詞。家屬只看得到 `family_bindings` 綁定的長輩；
  志工只看得到指派給自己或已開放搶的單；社工全看。**沒有角色＝什麼都看不到**（預設拒絕）。
- **寫**：op → 允許角色白名單 + 擁有權檢查。未知 op 一律拒絕。

兩個刻意的收緊，可以主動講出來：

1. **社工角色不能自助註冊。** `worker` 在授權表裡是「全看全改」，
   如果註冊表單自己選就能當社工，整套授權等於沒做。`jinsun-auth` 的 PostConfirmation
   只接受 `family` / `volunteer`，其餘一律退回 `family`——**這條實測過，申請 `worker` 確實被降級**。
2. **角色只認 Cognito Group，不認自訂屬性。** `custom:role` 使用者自己就能改。

實測擋下的越權：家屬改注記（社工限定）、志工改別人位置、家屬碰未綁定的長輩、未知 op。

---

### Q10. 長輩端沒有 UI，那它怎麼登入？那組帳密會不會是破口？

長輩端是**裝置帳號**，不是人的帳號——架構約束 2 說長輩不用 App、不用螢幕，
不可能叫他登入，所以帳密在 build 時用 `--dart-define` 注入、開網頁自動登入。

**破口風險用最小權限收斂**：那個帳號只綁定 elder-1，在 `/data/snapshot` 只看得到林阿春一位。
一台收音機就是一位長輩的，看得到別人反而才是授權破口。要再開一台就另建一組帳號綁對應長輩。

---

### Q11. 資料加密與保存多久？

| 面向 | 做法 |
|---|---|
| 傳輸 | 全鏈路 TLS 1.2+（IoT MQTT 8883、API Gateway HTTPS、Aurora Data API） |
| 靜態 | Aurora / DynamoDB / S3 加密；`radio_events.transcript` 與 `task_messages.text` 含個人對話內容 |
| 金鑰 | Aurora 主密碼由 Secrets Manager 託管輪替；外部服務 PAT 存 Lambda 環境變數，不進版控、不進前端封包 |
| 稽核 | Step Functions 執行歷史保留每一次升級的完整時間戳 |
| 語音檔 | ASR 完成即刪，不落地 |

⚠️ **一個要誠實承認的缺口**：CloudWatch Logs 目前**沒有設 retention，等於永久保留**。
正式上線前必須設定，這已列在賽後清理清單。

---

## D. AI 的部分

### Q12. 用了哪些模型？為什麼是這幾顆？

| 用途 | 模型 | 理由 |
|---|---|---|
| 意圖分類（量大、要快要便宜） | `us.anthropic.claude-haiku-4-5` | `llm()` 的 `fast` 參數已做好分流 |
| 陪伴對話、需求解析 | `us.anthropic.claude-sonnet-4-6` | 實測延遲 2.7–3.2s |

**誠實補充**：這個帳號只授權這兩顆。Opus 5 / Sonnet 5 / Opus 4.8 全部 `AccessDenied`，
換 API key、換區域都試過，是帳號層級的 entitlement。實測下來 Sonnet 4.6 的品質與延遲可接受。

一個值得講的細節，顯示我們真的在意長輩體驗：**換到 Bedrock 之後跑了語氣驗收**，
浮現兩個問題——模型會用「阿公／阿嬤」稱呼長輩（專案已定案移除稱謂），
以及回覆結尾加 emoji（**輸出直接送進 TTS，emoji 念不出來**）。兩者都已在 system prompt 修正。

---

### Q13. 台語怎麼辦？AWS 有支援嗎？

**沒有，這是我們自己補的。** Transcribe 沒有台語，Polly 也沒有閩南語音色。

| | 服務 | 誰在用 |
|---|---|---|
| **ASR** | SageMaker endpoint `breeze-asr-26`（`ml.g4dn.xlarge`，faster-whisper Breeze-ASR-26 fp16） | **收音機**（韌體直打，已接線） |
| **ASR（備援／網頁版）** | 外部 XCC Gateway，經 `jinsun-voice` 的 `POST /asr` 代理 | 長輩端網頁版；韌體裡保留為註解掉的備援 |
| **TTS 國語** | Amazon Polly Zhiyu neural（`jinsun-tts` Lambda） | 兩套環境共用 |
| **TTS 台語** | 外部 ATEN（`kws.oaselab.org`） | 裝置端直連 |

刻意**不把 ASR 換成 Transcribe**——它沒有台語，而語音是長輩唯一的輸入方式，
為了少一個外部相依而讓一半使用者不能用，不划算。所以我們自己在 SageMaker 上跑 Breeze-ASR-26。

Polly 那條有個實測細節可以講：**原始輸出偏小聲**（峰值只到 −10.0 dBFS），上板聽就是不清楚。
修法是在 Lambda 做峰值正規化到 −1 dBFS（實測 +9.0 dB、零削頂、長度不變所以語速沒跑掉）。
刻意不從韌體的音量調——那樣會連台語 TTS 一起變大聲。

**這條已經接起來了，而且值得主動講**——它是「不依賴別人的服務」的關鍵一步。
SageMaker 的傳輸層強制 AWS SigV4 簽章，所以 endpoint 不能直接 curl，也不該把 IAM 憑證燒進韌體。
我們補了一支 `jinsun-asr-openai` Lambda 當門面，把它開成 OpenAI 相容的
`POST /v1/audio/transcriptions`，韌體只要換 host 與金鑰、**組請求的程式碼一行都沒動**
（那支 Lambda 同時吃 `x-bf-vk` 與 `Authorization: Bearer`，刻意與原本的 gateway 對齊）。

換過來的好處：模型權重與 endpoint 都在自己的 AWS 帳號裡，不再依賴外部 gateway
（那顆是別人的服務、金鑰也是別人發的）。

一個實作上的坑值得講：門面轉發時 **ContentType 刻意標成 `octet-stream` 而不是原本的
`multipart/form-data`**——SageMaker 容器裡的 MMS 看到 multipart 會自己先把 parts 拆掉，
HF toolkit 接著只取名為 `body` 的那一份，handler 收到 `None` 就炸。

---

### Q14. LLM 會不會對長輩亂講話？譬如給錯誤的醫療建議？

**目前的防線是 system prompt，Bedrock Guardrails 還沒設——這是已知缺口。**

服務對象是失能長者，我們認為 Guardrails 是**必須有**的一層（醫療建議、金融詐騙誘導、自傷內容），
已列為下一階段的第一優先。

現階段的實質保護有兩層：
1. 緊急鏈路**不經過 LLM 判斷生死**——「20 秒沒回應就升級」是狀態機的硬規則，不是模型決定的。
   LLM 只負責「怎麼講話」，不負責「要不要救」。
2. 後台可即時切換 LLM 供應商，模型出問題可當場降級。
   ⚠️ 但這裡有個坑我們已經處理：後台選了機器做不到的供應商時會**靜默退回 mock**、
   長輩收到罐頭回覆而不易察覺，所以 Lambda 設 `LLM_PROVIDER_FORCE=bedrock` 跳過後台查詢。

---

### Q15. 為什麼跌倒偵測不放雲端做？雲端模型不是更強？

三個理由，第一個是不能妥協的：

1. **隱私。** 雲端推論代表影像必須上傳，架構約束 1 直接否決。
2. **延遲與可用性。** 網路斷了長輩就沒人守著，這對獨居長者是不可接受的失效模式。
3. **成本。** 24 小時串流影像的頻寬與 GPU 推論費用，不可能規模化到每一戶。

代價是裝置端算力有限。目前 AmebaPro2 的 NPU 已跑**本地音訊分類**（YAMNet），
求救聲會自動開始錄音；⚠️ **視覺跌倒推論本身尚未實作**——flash 已因 YAMNet 從 28% 跳到 84%
（`yamnet_fp16.nb` 就 8.7 MB），再加視覺模型幾乎塞不下，這是要誠實講的硬體限制。

---

## E. 可靠性與規模

### Q16. 家裡網路斷了怎麼辦？

分兩種情況誠實回答：

- **完全斷網**：雲端鏈路失效。實體 SOS 按鈕與本地燈號／鈴聲仍然作動，
  但無法通知家屬。這是目前的真實限制，緩解方向是 4G 備援模組。
- **短暫斷線**：MQTT 有 LWT（`jinsun/{serial}/status`），裝置離線雲端知道；
  重連後恢復訂閱。上行的 HTTPS 請求有重試。

---

### Q17. 20 秒真的準嗎？有實測數字嗎？

有，而且分兩層講比較誠實：

| 量測點 | 實測 |
|---|---|
| Step Functions 狀態機本身 | **T0+20.11s** |
| 家屬 App 畫面上看到「已升級」 | **T0+24s**（含 3 秒的變更指紋輪詢誤差） |
| MQTT 下行投遞 | 14ms |
| Bedrock 對話回應 | 2.7–3.2s |

完整的端到端鏈路已在真 AWS 上跑通並記錄：
疑似跌倒 → 家屬端 3 秒內看到「確認中」→ 20 秒升級 → 開派遣單並就近派給志工
→ 志工接單（重複接單回 409）→ 家屬↔志工聊天 → 到場 → presigned S3 上傳結案照片
→ 結案 → 時間銀行 +21 分 → 長輩燈號回綠。

⚠️ 一個要誠實標註的：上述驗證多數是用 curl 與檢查產出檔完成的，
**UI 層還沒有由真人在瀏覽器完整走過一遍**。這個缺口咬過我們一次——
三端在瀏覽器打 `/data/*` 全部失敗，因為 `OPTIONS` preflight 被 `$default` 路由吃掉回 404，
而 curl 不發 preflight 所以測不出來。已修，並加進 `smoke-test.sh` 的第 3 項。

---

### Q18. 一台變一萬台會怎樣？瓶頸在哪？

先講**不會是瓶頸的**：API Gateway、Lambda、IoT Core、DynamoDB、S3、CloudFront 都隨用量水平擴展。
Step Functions 每個事件一條獨立 execution，彼此不影響。

**會先撞牆的三個**，按先後順序：

1. **Aurora 的 ACU 上限**（目前 0.5–4）。快照查詢是一整句 `json_agg`，長輩數一多會變重。
   解法是提高上限 + 讀取走 read replica，schema 不必動。
2. **輪詢的放大效應**。一萬個 App 每 3 秒打一次 `/data/version` ≈ 3300 QPS。
   這是必須升級成真訂閱的臨界點——介面已經預留好（Q5）。
3. **SageMaker GPU endpoint**。台語 ASR 的 GPU 常開約 $530/月，要改成
   Asynchronous Inference（無請求縮到 0 台）或多台 auto scaling。

規模化的正解不是重寫，而是**把已經預留好的三個開關打開**。

---

### Q19. 成本多少？

Demo 規模（10 台裝置、20 位使用者）估算 **≈ $130–220 / 月**，最大的兩塊是：

| 服務 | 月成本 | 備註 |
|---|---|---|
| SageMaker ASR | $60–90（定時起停）／~$530（常開） | 最大單一支出。⚠️ 它在**正式鏈路上**，起停期間長輩講話沒人聽得懂——demo 前務必確認是 InService |
| Bedrock | $20–45 | Haiku 分類 + Sonnet 對話 |
| Aurora Serverless v2 | $20–45 | **唯一持續計費**，min 0.5 ACU 是為了黃金窗刻意付的 |
| 其餘（IoT / API GW / Lambda / DynamoDB / S3 / CloudFront / Cognito） | 合計 < $10 | 多數在免費額度內 |

成本控制的三招都已內建：意圖分類走 Haiku（`fast` 參數已分流）、
SageMaker 用 EventBridge Scheduler 定時起停、另設 AWS Budgets 告警。

---

## F. 圖上細節的追問

### Q20. 為什麼裝置有兩條線進雲？一條不行嗎？

不行，因為兩條線的**方向性**不同：

- **上行走 HTTPS**：長輩主動說話 → 要**同步**拿到要立刻播的那一句。請求／回應模型最自然。
- **下行走 MQTT**：雲端要**主動**對長輩說話（20 秒升級後的「志工已在路上」）。
  HTTPS 做不到 server push，而 Render 那類 PaaS 只開 443 也擺不了 broker——
  這正是正式環境被迫用公共 broker 會合的原因。IoT Core 一次解決連線與憑證認證兩件事。

### Q21. 圖上寫 publish / subscribe，那是廣播嗎？一台講話全部都聽得到？

**不是廣播，是 per-device topic 的點對點下發。** topic 是 `jinsun/{serial}/cmd`，
`{serial}` 就是那台機器的序號，而 IoT Policy 用 Thing name 變數把裝置鎖死在自己的 topic 上（見 Q8），
訂別人的會被拒。另外 MQTT client id 必須等於 Thing 名稱，憑證也要 attach 到同一個 Thing。

### Q22. 為什麼一定要 CloudFront？S3 靜態網站不就好了？

**因為 S3 網站端點只有 HTTP，而瀏覽器在非 HTTPS 下不給硬體權限。**

- 志工端的 GPS 上報與家屬地圖的志工位置會整條失效。
- 長輩端更嚴重：麥克風同樣要 HTTPS，走 S3 端點的話「按住說話」那顆大按鈕**整個是啞的**。

### Q23. 圖上的 S3 有兩個，差在哪？

左邊那個是**四端 Flutter Web 的靜態站**（`jinsun-{family,volunteer,admin,elder}-web`），
右邊那個是**結案證明照片**（`jinsun-proofs`）——志工到場後拍照結單，走 presigned PUT
**直傳、不經 Lambda**，避免大檔案佔用函式的記憶體與執行時間。

### Q24. 社工後台的 Excel 匯出在圖上哪裡？

它是 `jinsun-data` Lambda 的一條路徑：查 Aurora → 產 xlsx → 寫 S3 → 回 presigned URL。
這是**政府申報的硬需求**（架構約束 4），不是加分項。
資料量放大到全縣市年度申報時，路線是 Aurora → S3(Parquet) → Athena → Step Functions 組表。

---

## G. 誠實面對的缺口

評審一定會問「還有什麼沒做」。主動講完整比被問出來好，也更能顯示我們知道自己在哪。

| 項目 | 狀態 | 影響與計畫 |
|---|---|---|
| **視覺跌倒推論** | ❌ 未實作 | 目前靠本地音訊分類（求救聲）＋ SOS 按鈕觸發。flash 已用到 84%，再塞視覺模型是硬體瓶頸 |
| **Bedrock Guardrails** | ❌ 未設 | 服務對象是失能長者，這是下一階段第一優先（見 Q14） |
| **SNS 背景推播** | ❌ 未接 | `device_tokens` 已會寫進 Aurora，發送端未接。目前 App 在前景才收得到 |
| **AppSync 真訂閱** | ❌ 未建 | **刻意的取捨**（見 Q5），介面已預留 |
| **UI 層真人驗證** | ⚠️ 未完整走過 | 後端 API 全綠但瀏覽器可能另有問題，已被 CORS preflight 咬過一次 |
| **CloudWatch Logs retention** | ⚠️ 未設 | 等於永久保留，正式上線前必須設定 |
| **ECS Fargate 備援路徑** | ⚠️ 已改寫但未實跑 | 不確定帳號 SCP 是否放行 `ecs:*` |

---

### Q25. 為什麼還有另一套 Supabase 環境並存？不會混淆嗎？

**這是刻意的，而且兩套環境完全不共用資料庫。**

AWS 這套（`cloud/aws/`）用自己的 Aurora，與正式環境的 Supabase 徹底斷開。
理由是如果指向同一個資料庫會有三個問題：播報打架（兩邊的 worker 都反應同一筆變化）、
測試污染正式資料（跑一次升級測試就在正式環境開出真的派遣單、推播到真實手機）、
以及那根本不算兩套環境——資料層是單點，一邊改壞 schema 兩邊一起死。

切換點收斂到**兩個地方**，其餘程式碼完全共用：
四端靠 `apps/packages/core/lib/src/backend_factory.dart`（`--dart-define=BACKEND=aws`），
韌體靠 `.ino` 開頭一個 `#define BACKEND_AWS`（topic、payload、QoS、LWT 全部不變）。

唯一兩套共用的是 `jinsun-tts`（Polly）與 ASR gateway——它們是**無狀態服務呼叫、沒有資料落地**，
不違反「不共用資料庫」的原則。

---

## H. 一頁速查表

**最可能被問的五題與一句話答案：**

| 問題 | 一句話 |
|---|---|
| 為什麼 Step Functions？ | 計時器不能活在單一行程記憶體裡，行程一重啟長輩就永遠等不到升級 |
| 為什麼不是訂閱？ | 訂閱對最重要的那條鏈路不會響，而且會把失敗點加在最不能失敗的地方 |
| 影像會上雲嗎？ | 不會，而且是在 IAM 層強制——裝置憑證根本沒有媒體上傳權限 |
| 20 秒準嗎？ | 狀態機 T0+20.11s，家屬端看到是 T0+24s（含 3 秒輪詢誤差） |
| 還有什麼沒做？ | 視覺跌倒推論、Bedrock Guardrails、SNS 背景推播——見 §G |

**三個可以主動秀出來的實測細節**（顯示不是紙上談兵）：

1. 相對 `Wait` 會累積開銷、實測超窗到 21.55s，改絕對時間戳才穩定在 20.11s。
2. `JSON.stringify` 會丟掉 `undefined`——裝置依契約不送 `elder_id`，
   欄位消失導致 ASL 找不到路徑，**每一次真實升級都會炸**。所有進狀態機的欄位一律 `?? null`。
3. `jinsun-progress` 移除 Supabase 依賴時 import 沒清乾淨，Lambda **載入即死**，
   症狀是「什麼都沒發生」——三端畫面正常、資料庫正常，只有長輩那端永遠沒聲音，
   錯誤只進 CloudWatch 的 `INIT_REPORT`，不回到任何呼叫端。

**一句話收尾**：這套系統把「感知 → 決策 → 行動 → 回報」做成閉環，
而 AWS 在其中負責的是**最不能失手的那 20 秒**——
用 Step Functions 保住它跨行程存活，用 IoT Core 保住那句話一定送得到，
用 IAM 保住影像永遠不會離開那個家。

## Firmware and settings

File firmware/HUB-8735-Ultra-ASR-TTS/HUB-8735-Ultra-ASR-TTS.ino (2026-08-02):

#include <sys/time.h>
#include "StreamIO.h"
#include "AudioStream.h"
#include "AudioEncoder.h"
#include "MP4Recording.h"
#include "WiFi.h"
#include "AmebaFatFS.h"
#include "Base64.h"
#include <ArduinoJson.h>
#include <MAX98357.h>
#include <PubSubClient.h>
#include <errno.h>
#include "NNAudioClassification.h"
// 521 類 YAMNet 標籤表(從 SDK 的 AudioClassification 範例複製過來,索引由訓練時固定)。
// 只拿來把 class id 轉成人看得懂的名字寫進 log——實際要不要反應由下面自己的白名單決定,
// 不用它的 filter 欄位(那是範例的做法,改 521 行的表比讀一份白名單難維護太多)。
#include "AudioClassList.h"

// ===== 機密設定（不進版控）=====
// 把 secrets.h.example 複製成 secrets.h（同資料夾，已在 .gitignore）並填入實際值。
// 沒有這個檔也編得過，但用的是下面的佔位符 → 連不上網、AWS IoT 也不會連。
#if defined(__has_include)
#  if __has_include("secrets.h")
#    include "secrets.h"
#  endif
#endif
#ifndef SECRET_WIFI_SSID
#define SECRET_WIFI_SSID "xxx"
#endif
#ifndef SECRET_WIFI_PASS
#define SECRET_WIFI_PASS "xxx"
#endif
#ifndef SECRET_ASR_API_KEY
#define SECRET_ASR_API_KEY "sk-jinsun-"    // 佔位符;實際值放 secrets.h(見下方 ASR 區塊)
#endif

// ===== 後端環境切換（改這一行就好）=====
// 0 = 正式環境：Render voice server + mqttgo.io + Supabase
// 1 = AWS 平行環境：API Gateway + Lambda + Step Functions + IoT Core + Aurora
//
// ⚠️ 兩套環境**不共用資料庫**：切過去之後這台裝置的事件只會出現在 AWS 那三端網址上，
//    正式環境的家屬 App 看不到（反之亦然）。交接說明見 docs/requirements/aws-handoff.md。
// 契約（topic、payload、QoS、LWT、/voice 的請求與回應）兩邊完全相同，只有端點與憑證不同。
#define BACKEND_AWS 1

char ssid[] = SECRET_WIFI_SSID;    // your network SSID (name)
char pass[] = SECRET_WIFI_PASS;    // your network password
int status = WL_IDLE_STATUS;

// ===== ASR(語音轉文字)=====
// 現用:自家的 SageMaker endpoint `breeze-asr-26`(faster-whisper Breeze-ASR-26 fp16),
// 由 jinsun-asr-openai Lambda 開成 OpenAI 相容的 /v1/audio/transcriptions。
// 部署:bash cloud/aws/scripts/deploy-asr-openai.sh
//
// 換過來的好處:不再依賴外部 gateway(XCC 那顆是別人的服務、金鑰也是別人發的),
// 模型權重與 endpoint 都在自己帳號裡。
//
// 刻意**不用 #if BACKEND_AWS 包起來**,理由與下方國語 TTS 完全相同:
// 這是無狀態的服務呼叫、沒有資料落地,不違反「兩套環境不共用資料庫」。
//
// ⚠️ 認證標頭不用改:那支 Lambda 同時吃 `x-bf-vk` 與 `Authorization: Bearer`,
//    刻意與 XCC Gateway 對齊,所以下面組請求的程式碼一行都不用動。
// ⚠️ 金鑰換人發了:AWS 這條是 `sk-jinsun-…`(deploy-asr-openai.sh 產生並印出),
//    不是 XCC 的 `sk-bf-…`。secrets.h 的 SECRET_ASR_API_KEY 要一起換。
// ⚠️ 音檔上限 4.5MB、單次請求上限 30 秒(API Gateway 整合逾時硬上限)。
//    板子最長錄 30 秒 ≈ 1MB,在範圍內。
String api_key = SECRET_ASR_API_KEY;
char api_server[] = "yr0ep335el.execute-api.us-west-2.amazonaws.com";
String api_path = "/v1/audio/transcriptions";
String model = "breeze-asr-26";

// —— 舊的 XCC Gateway(保留備援)——
// SageMaker endpoint 是 GPU 機型、會被 teardown 收掉;真的收掉時把上面四行註解、
// 改用下面四行即可切回去(路徑與標頭都相同,只有 host / model / 金鑰不同)。
// String api_key = SECRET_ASR_API_KEY;               // Groq - > https://console.groq.com/keys
// char api_server[] = "llm-gateway.xcc.tw";             // Groq - > api.groq.com
// String api_path = "/v1/audio/transcriptions";     // Groq - > /openai/v1/audio/transcriptions
// String model = "paulpengtw/faster-whisper-Breeze-ASR-26";                       // Groq - > whisper-large-v3-turbo or whisper-large-v3

#define FILENAME "test"
String FILENAME_EXT = String(FILENAME)+".mp4";
int recordSeconds = 30;         // 最長錄音上限(秒);可按鈕/序列輸入提前結束

// ===== TTS(文字轉語音):兩顆服務,依下行的 lang 分流 =====
// 台語:ATEN。⚠️ 這顆是**台語模型**,而且端點不吃 voice/lang 參數,
//       所以它只會講台語 —— 沒辦法拿它來念國語。
char tts_server[] = "kws.oaselab.org";
String tts_path = "/nutntweng/tts/aten/";

// 國語:Amazon Polly(Zhiyu),經 API Gateway 的 jinsun-tts Lambda。
// 回應直接是 WAV bytes(不是 ATEN 那種 JSON URL),POST 完就能邊收邊播,
// 少一次 TLS 握手(板子上一次握手就要幾百毫秒)。
// 部署:bash cloud/aws/scripts/deploy-tts.sh
//
// 刻意**不用 #if BACKEND_AWS 包起來**:TTS 是無狀態的服務呼叫、沒有資料落地,
// 不違反「兩套環境不共用資料庫」——上面的 ASR 也是同一個判斷。
// 這樣 Render 環境同樣念得出國語。
char tts_mandarin_server[] = "yr0ep335el.execute-api.us-west-2.amazonaws.com";
String tts_mandarin_path = "/tts";

// ===== 雲端語音 Agent server(上行 POST /voice) =====
// 契約見 docs/requirements/hardware-integration.md §3①:
//   請求 {device_serial, text} 或 {device_serial, event:"sos"|"fall_suspected"|…}
//   回應 {reply, intent, action:{command}, lang}
// 「大腦」在雲端(意圖分類、問診、20 秒升級計時、派遣志工),裝置只負責
// 收音、上報事件、發聲。原本直連 Gemini 的做法已換成這條,長輩的話才進得了
// 急救狀態機——直連 LLM 時雲端根本不知道有人在求救。
#if BACKEND_AWS
// AWS:API Gateway($default 路由 → jinsun-voice Lambda)。契約與 Render 那台逐欄位相同。
char voice_server[] = "yr0ep335el.execute-api.us-west-2.amazonaws.com";
// Lambda 冷啟動約 2–5 秒;API Gateway 的整合逾時上限本來就是 30 秒,等更久沒有意義。
const unsigned long voice_timeout_ms = 30000;
#else
char voice_server[] = "jinsun-voice-server-mg1f.onrender.com";
// Render 免費方案閒置會休眠,冷啟動可能 30–60 秒才回應
const unsigned long voice_timeout_ms = 60000;
#endif
String voice_path = "/voice";
// device_serial 全程固定,同時是 MQTT client id 與 topic 的一部分。
// 正式版由 BLE 配網寫入;現在先硬編碼(JS-0001 是資料庫既有種子,可直接對測)。
//
// ⚠️ 走 AWS 時這個字串有第三個身分:IoT **Thing 名稱**。IoT Policy 用
//    ${iot:Connection.Thing.ThingName} 限縮 client id 與 topic(cloud/aws/iot/device-policy.json),
//    所以 device_serial ≠ Thing 名稱 → 連線直接被切斷,而且不會有任何錯誤訊息。
//    AWS 上已建好的 Thing 是 JS-0001 與 JS-REAL-0001,燒進去的憑證要 attach 到同一個。
String device_serial = "JS-0002";

// ===== MQTT 下行(server publish → 裝置) =====
// 契約見 §3②:訂閱 jinsun/{serial}/cmd(QoS 1)、keep-alive 30s、
// 斷線指數退避重連(1s→2s→…→30s)、LWT jinsun/{serial}/status = "offline"。
// 為什麼要外部 broker:Render 這類 PaaS 只對外開 443,server 內嵌的 aedes(1883)
// 從公網進不來 → server 與裝置各自連上同一顆公共 broker 會合(契約完全不變)。
// AWS 這邊則是 IoT Core 當 broker,jinsun-speak Lambda 負責 publish;順帶補掉
// 「公共 broker 無認證、任何人都能對 jinsun/# 發指令」這個資安洞。
#if BACKEND_AWS
// AWS IoT Core 的 ATS endpoint(`aws iot describe-endpoint --endpoint-type iot:Data-ATS`)。
// 8883 = X.509 雙向 TLS。不要改成 443——443 要求 ALPN `x-amzn-mqtt-ca`,這個核心送不出去。
char mqtt_server[] = "a2zyk2buv4tih2-ats.iot.us-west-2.amazonaws.com";
#else
char mqtt_server[] = "mqttgo.io";
#endif
const int mqtt_port = 8883;    // 一律走 TLS:實測此核心純 TCP(WiFiClient)收不到任何資料
// AWS IoT 允許的 keep-alive 是 30–1200 秒,30 剛好是下限(送 1–29 會被拉到 30)。
const int mqtt_keepalive = 30;
// topic 兩套環境完全相同,jinsun-speak Lambda publish 的也是這一條。
String cmd_topic = "jinsun/" + device_serial + "/cmd";
String status_topic = "jinsun/" + device_serial + "/status";

// ===== 裝置憑證(只有 AWS IoT 需要:X.509 雙向 TLS)=====
// 用下列指令重簽一組並掛上 policy 與 thing(私鑰無法從 AWS 取回,遺失就重簽)。
// 指令刻意包在 block 註解裡:shell 的行尾 \ 在 // 註解中會把下一行一起接進註解
// (-Wcomment),改回 // 會警告,而且哪天最後一行下面擺了程式碼就會被吃掉。
/*
  aws iot create-keys-and-certificate --set-as-active \
    --certificate-pem-outfile device.cert.pem --private-key-outfile device.key.pem \
    --public-key-outfile device.public.pem --query certificateArn --output text > cert.arn
  aws iot attach-policy --policy-name JinsunDevicePolicy --target "$(cat cert.arn)"
  aws iot attach-thing-principal --thing-name JS-0001 --principal "$(cat cert.arn)"
*/
// 兩個檔案的內容貼進 secrets.h(見 secrets.h.example)。**憑證與私鑰絕對不要進 git。**
#ifndef SECRET_AWS_DEVICE_CERT
#define SECRET_AWS_DEVICE_CERT "PASTE device.cert.pem HERE (see secrets.h.example)\n"
#endif
#ifndef SECRET_AWS_DEVICE_KEY
#define SECRET_AWS_DEVICE_KEY "PASTE device.key.pem HERE (see secrets.h.example)\n"
#endif
char* device_cert_pem = (char*)SECRET_AWS_DEVICE_CERT;
char* device_key_pem = (char*)SECRET_AWS_DEVICE_KEY;

// 憑證還是佔位符時要**在連線前就擋下來並講清楚**:AWS IoT 對認證/授權失敗的反應是
// 直接切斷 TCP,不會回 CONNACK 錯誤碼,PubSubClient 只會回 rc=-2,症狀長得跟
// 「網路不穩」一模一樣(aws-handoff.md §5),照著查會查錯方向。
bool deviceCertReady()
{
    return strncmp(device_cert_pem, "-----BEGIN ", 11) == 0
           && strstr(device_key_pem, "-----BEGIN ") != NULL;
}

// mqttgo.io 憑證由 Let's Encrypt 簽發,鏈根為 ISRG Root X1(下面這張)。
// ⚠️ Let's Encrypt 是 90 天短效憑證,而本板無 RTC/NTP、開機硬設時鐘(見 setup()):
//    重燒韌體時務必把 tv.tv_sec 更新到接近當天,否則會被判「憑證尚未生效」而連不上。
char* isrg_root_x1 =
    "-----BEGIN CERTIFICATE-----\n"
    "MIIFazCCA1OgAwIBAgIRAIIQz7DSQONZRGPgu2OCiwAwDQYJKoZIhvcNAQELBQAw\n"
    "TzELMAkGA1UEBhMCVVMxKTAnBgNVBAoTIEludGVybmV0IFNlY3VyaXR5IFJlc2Vh\n"
    "cmNoIEdyb3VwMRUwEwYDVQQDEwxJU1JHIFJvb3QgWDEwHhcNMTUwNjA0MTEwNDM4\n"
    "WhcNMzUwNjA0MTEwNDM4WjBPMQswCQYDVQQGEwJVUzEpMCcGA1UEChMgSW50ZXJu\n"
    "ZXQgU2VjdXJpdHkgUmVzZWFyY2ggR3JvdXAxFTATBgNVBAMTDElTUkcgUm9vdCBY\n"
    "MTCCAiIwDQYJKoZIhvcNAQEBBQADggIPADCCAgoCggIBAK3oJHP0FDfzm54rVygc\n"
    "h77ct984kIxuPOZXoHj3dcKi/vVqbvYATyjb3miGbESTtrFj/RQSa78f0uoxmyF+\n"
    "0TM8ukj13Xnfs7j/EvEhmkvBioZxaUpmZmyPfjxwv60pIgbz5MDmgK7iS4+3mX6U\n"
    "A5/TR5d8mUgjU+g4rk8Kb4Mu0UlXjIB0ttov0DiNewNwIRt18jA8+o+u3dpjq+sW\n"
    "T8KOEUt+zwvo/7V3LvSye0rgTBIlDHCNAymg4VMk7BPZ7hm/ELNKjD+Jo2FR3qyH\n"
    "B5T0Y3HsLuJvW5iB4YlcNHlsdu87kGJ55tukmi8mxdAQ4Q7e2RCOFvu396j3x+UC\n"
    "B5iPNgiV5+I3lg02dZ77DnKxHZu8A/lJBdiB3QW0KtZB6awBdpUKD9jf1b0SHzUv\n"
    "KBds0pjBqAlkd25HN7rOrFleaJ1/ctaJxQZBKT5ZPt0m9STJEadao0xAH0ahmbWn\n"
    "OlFuhjuefXKnEgV4We0+UXgVCwOPjdAvBbI+e0ocS3MFEvzG6uBQE3xDk3SzynTn\n"
    "jh8BCNAw1FtxNrQHusEwMFxIt4I7mKZ9YIqioymCzLq9gwQbooMDQaHWBfEbwrbw\n"
    "qHyGO0aoSCqI3Haadr8faqU9GY/rOPNk3sgrDQoo//fb4hVC1CLQJ13hef4Y53CI\n"
    "rU7m2Ys6xt0nUW7/vGT1M0NPAgMBAAGjQjBAMA4GA1UdDwEB/wQEAwIBBjAPBgNV\n"
    "HRMBAf8EBTADAQH/MB0GA1UdDgQWBBR5tFnme7bl5AFzgAiIyBpY9umbbjANBgkq\n"
    "hkiG9w0BAQsFAAOCAgEAVR9YqbyyqFDQDLHYGmkgJykIrGF1XIpu+ILlaS/V9lZL\n"
    "ubhzEFnTIZd+50xx+7LSYK05qAvqFyFWhfFQDlnrzuBZ6brJFe+GnY+EgPbk6ZGQ\n"
    "3BebYhtF8GaV0nxvwuo77x/Py9auJ/GpsMiu/X1+mvoiBOv/2X/qkSsisRcOj/KK\n"
    "NFtY2PwByVS5uCbMiogziUwthDyC3+6WVwW6LLv3xLfHTjuCvjHIInNzktHCgKQ5\n"
    "ORAzI4JMPJ+GslWYHb4phowim57iaztXOoJwTdwJx4nLCgdNbOhdjsnvzqvHu7Ur\n"
    "TkXWStAmzOVyyghqpZXjFaH3pO3JLF+l+/+sKAIuvtd7u+Nxe5AW0wdeRlN8NwdC\n"
    "jNPElpzVmbUq4JUagEiuTDkHzsxHpFKVK7q4+63SM1N95R1NbdWhscdCb+ZAJzVc\n"
    "oyi3B43njTOQ5yOf+1CceWxG1bQVs5ZufpsMljq4Ui0/1lvh+wjChP4kqKOJ2qxq\n"
    "4RgqsahDYVvTH9w7jXbyLeiNdd8XM2w9U/t7y0Ff/9yi0GE44Za4rF2LN9d11TPA\n"
    "mRGunUHBcnWEvgJBQl9nJEiU0Zsnvgc/ubhPgXRR4Xq37Z0j4r7g1SgEEzwxA57d\n"
    "emyPxgcYxn/eR44/KJ4EBs+lVDR3veyJm+kXQ99b21/+jh5Xos1AnX5iItreGCc=\n"
    "-----END CERTIFICATE-----\n";

// AWS IoT 的 ATS endpoint 由 Amazon Root CA 1 簽發(有效期到 2038,不像 Let's Encrypt 會
// 每 90 天換一次;但下面設系統時間那段還是不能省——時鐘落在**裝置憑證**的
// notBefore 之前一樣會驗不過,而裝置憑證是「重簽當天」才生效的)。
// 來源:https://www.amazontrust.com/repository/AmazonRootCA1.pem
char* amazon_root_ca1 =
    "-----BEGIN CERTIFICATE-----\n"
    "MIIDQTCCAimgAwIBAgITBmyfz5m/jAo54vB4ikPmljZbyjANBgkqhkiG9w0BAQsF\n"
    "ADA5MQswCQYDVQQGEwJVUzEPMA0GA1UEChMGQW1hem9uMRkwFwYDVQQDExBBbWF6\n"
    "b24gUm9vdCBDQSAxMB4XDTE1MDUyNjAwMDAwMFoXDTM4MDExNzAwMDAwMFowOTEL\n"
    "MAkGA1UEBhMCVVMxDzANBgNVBAoTBkFtYXpvbjEZMBcGA1UEAxMQQW1hem9uIFJv\n"
    "b3QgQ0EgMTCCASIwDQYJKoZIhvcNAQEBBQADggEPADCCAQoCggEBALJ4gHHKeNXj\n"
    "ca9HgFB0fW7Y14h29Jlo91ghYPl0hAEvrAIthtOgQ3pOsqTQNroBvo3bSMgHFzZM\n"
    "9O6II8c+6zf1tRn4SWiw3te5djgdYZ6k/oI2peVKVuRF4fn9tBb6dNqcmzU5L/qw\n"
    "IFAGbHrQgLKm+a/sRxmPUDgH3KKHOVj4utWp+UhnMJbulHheb4mjUcAwhmahRWa6\n"
    "VOujw5H5SNz/0egwLX0tdHA114gk957EWW67c4cX8jJGKLhD+rcdqsq08p8kDi1L\n"
    "93FcXmn/6pUCyziKrlA4b9v7LWIbxcceVOF34GfID5yHI9Y/QCB/IIDEgEw+OyQm\n"
    "jgSubJrIqg0CAwEAAaNCMEAwDwYDVR0TAQH/BAUwAwEB/zAOBgNVHQ8BAf8EBAMC\n"
    "AYYwHQYDVR0OBBYEFIQYzIU07LwMlJQuCFmcx7IQTgoIMA0GCSqGSIb3DQEBCwUA\n"
    "A4IBAQCY8jdaQZChGsV2USggNiMOruYou6r4lK5IpDB/G/wkjUu0yKGX9rbxenDI\n"
    "U5PMCCjjmCXPI6T53iHTfIUJrU6adTrCC2qJeHZERxhlbI1Bjjt/msv0tadQ1wUs\n"
    "N+gDS63pYaACbvXy8MWy7Vu33PqUXHeeE6V/Uq2V8viTO96LXFvKWlJbYK8U90vv\n"
    "o/ufQJVtMVT8QtPHRh8jrdkPSHCa2XV4cdFyQzR1bldZwgJcJmApzyMZFo6IQ6XU\n"
    "5MsI+yMRQ+hDKXJioaldXgjUkK642M4UwtBV8ob2xJNDd2ZhwLnoQdeXeGADbkpy\n"
    "rqXRfboQnoZsG4q5WTP468SQvvG5\n"
    "-----END CERTIFICATE-----\n";

#if BACKEND_AWS
char* mqtt_root_ca = amazon_root_ca1;
#else
char* mqtt_root_ca = isrg_root_x1;
#endif

// D12 被 I2S 的 LRC 佔用、D13 是閃光燈 PWM(恆為 LOW),按鈕用 D9。
// 按鈕接 D9 與 GND,用 INPUT_PULLUP(按下 = LOW)。
const int buttonPin = 9;          // the number of the pushbutton pin
const int buttonPressInterval = 1000;          // 按住 1 秒觸發

AmebaFatFS fs;
WiFiClient wifiClient;

// MQTT 下行:獨立一條 TLS 連線常駐(與 ASR/TTS/voice 的短連線互不干擾)
WiFiSSLClient mqttNet;
PubSubClient mqtt(mqttNet);

// 指令佇列:MQTT callback 只把 payload 丟進來就返回,實際發聲回主迴圈才做。
// callback 內若直接播 TTS(要連兩次 HTTPS、播放又是阻塞的),會卡住 MQTT
// 收訊迴圈導致 keep-alive 逾時斷線,而且斷線重連後 broker 會重送同一則(QoS 1),
// 變成無限循環播報。
#define CMD_QUEUE_SIZE 6
String cmdQueue[CMD_QUEUE_SIZE];
int cmdHead = 0;
int cmdCount = 0;

// MAX98357 I2S 揚聲器:BCLK→D24、LRC→D12、DIN→D11、SD_MODE→D10
// (同時佔用 D22/D23,板載按鈕不可用)
MAX98357 amp;
// volume_up/volume_down 指令會調整這個值。
// ⚠️ 這是**兩顆 TTS 共用**的總音量，不要拿它補單一服務的音量差——Polly 那條路曾經
// 上板聽起來偏小聲(Polly 原始輸出峰值只到 −10 dBFS)，那是在 jinsun-tts Lambda 端做
// 峰值正規化解決的;從這裡調會連 ATEN(台語)一起變大聲，而且只剩 0.2 可加。
float ampVolume = 0.8;
String lastSpokenText = "";        // repeat 指令要重播的內容
String lastSpokenLang = "mandarin";

char buf[512];
char *p;
String filepath;
File file;

// Default audio preset configurations:
// 0 :  8kHz Mono Analog Mic
// 1 : 16kHz Mono Analog Mic
// 2 :  8kHz Mono Digital PDM Mic
// 3 : 16kHz Mono Digital PDM Mic
//
// HUB 8735 Ultra 板載麥克風是數位 PDM，用 1(類比) 會錄到一片死寂（實測 -74dBFS）。
// 改用 3 = 16kHz Mono Digital PDM Mic。若換板子或外接類比麥克風，再改回 1。
// 順帶一提:preset 3 展開後就是 AudioSetting(16000, 1, USE_AUDIO_LEFT_DMIC),
// 與 SDK 的 AudioClassification 範例逐欄位相同——YAMNet 只吃 16kHz,所以錄音與
// 聲音偵測可以共用同一份設定、同一顆麥克風,不用開第二條音訊管線。
AudioSetting configA(3);
Audio audio;
AAC aac;
MP4Recording mp4;
StreamIO audioStreamer2(1, 1);    // 1 Input AAC -> 1 Output MP4
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
void loop()
{
    // MQTT:維持連線(斷了就退避重連)並收下行指令
    mqttPump();
    // 消化佇列裡的下行指令(在這裡播,不在 callback 裡播)。
    // 錄音中先不播,免得自己的喇叭聲被麥克風錄進去。
    if (recordingstate != 1) {
        drainCommandQueue();
    }

#if ENABLE_SOUND_DETECTION
    // 本地聲音事件:NN 執行緒只放旗標,真正的動作(播提示音、開錄音、上報)在這裡做
    pumpSoundDetection();
#endif

    // Button state
    // 診斷 log:每個電平邊緣印一次,帶上「維持了多久」——按鈕行為出問題時,
    // 從這裡可以直接看出是彈跳(極短的按下/放開)、還是狀態機判斷有誤。
    int newButtonState = digitalRead(buttonPin);
    if (newButtonState != buttonState) {
        unsigned long held = millis() - buttonPressTime;
        if (newButtonState == LOW) {
            Serial.println("[BTN] ↓ 按下（前一次放開後隔了 " + String(held) + " ms）");
        } else {
            Serial.println("[BTN] ↑ 放開（按住了 " + String(held) + " ms）");
        }
        buttonPressTime = millis();
        longPressLogged = false;    // 新的一次按壓,長按 log 重新武裝
    }
    // update button state
    buttonState = newButtonState;

    // update recording state(順便印出轉換,對照按鈕事件才知道誰觸發了誰)
    int newRecordingState = (int)(mp4.getRecordingState());
    if (newRecordingState != recordingstate) {
        Serial.println("[BTN] 錄音狀態 " + String(recordingstate) + " → " + String(newRecordingState)
                       + "（0=停止 1=錄音中）");
    }
    recordingstate = newRecordingState;

    // check if the button has been held for at least buttonPressInterval
    if (buttonState == LOW && millis() - buttonPressTime >= buttonPressInterval) {
        // button has been held past the threshold
        buttonPressedLongEnough = true;
    } else {
        // button was released before the threshold
        buttonPressedLongEnough = false;
    }
    // if button has been held past the threshold
    if (buttonPressedLongEnough) {
        if (!longPressLogged) {
            Serial.println("[BTN] 按住已達 " + String(buttonPressInterval) + " ms 門檻"
                           + "（此刻 recordingstate=" + String(recordingstate) + "）");
            longPressLogged = true;
        }
        if (recordingstate == 1) {
            digitalWrite(LED_BUILTIN, HIGH);
        } else {
            // ⚠️ 這行如果連續刷出很多筆,代表同一次按壓重複觸發了 mp4.begin():
            //    buttonPressTime 只在「電平改變」時更新,所以按著不放的話
            //    millis()-buttonPressTime 會一直 >= 門檻,這個分支每輪都會進來,
            //    直到 mp4 回報 recordingstate=1 為止。
            Serial.println("[BTN] → 開始錄音（本次已按住 "
                           + String(millis() - buttonPressTime) + " ms）");
            startRecording(recordSeconds, "按鈕長按");
            Serial.println("Recording (press button again or type 'stop' to finish)");
        }
    }

    // 錄音中:按鈕放開後「再按一下」→ 提前結束錄音
    if (recordingstate == 1) {
        if (buttonState == HIGH) {
            if (!stopArmed) {
                Serial.println("[BTN] 已武裝:再按一下即可結束錄音");
            }
            stopArmed = true;
        } else if (stopArmed && prevButtonLevel == HIGH) {
            Serial.println("[BTN] → 停止錄音（第二次按下的瞬間觸發）");
            mp4.end();    // 走 mp4RecordingStop,檔案一樣會正常收尾
            stopArmed = false;
        }
    }
    prevButtonLevel = buttonState;

    // 序列輸入:stop=提前結束錄音;sos/fall=模擬事件上報(沒有實體 SOS 鍵與
    // 相機時也能跑完整條「感知→決策→行動」鏈路,demo 用)
    while (Serial.available()) {
        char c = Serial.read();
        if (c == '\n') {
            serialLine.trim();
            if (recordingstate == 1 && serialLine == "stop") {
                Serial.println("Stop recording (serial)");
                mp4.end();
            } else if (serialLine == "sos") {
                sendEvent("sos");
            } else if (serialLine == "fall") {
                sendEvent("fall_suspected");
            }
#if ENABLE_SOUND_DETECTION
            // 聲音偵測的模擬觸發:直接偽造 NN callback 的產物,走完全相同的下游邏輯。
            // 沒有這兩個指令,要驗「撞擊 + 求救 = 跌倒」就得真的在辦公室摔東西再尖叫,
            // 而且門檻沒調好時根本分不出是判斷邏輯錯還是模型沒聽到。
            else if (serialLine == "bang") {
                pendingImpactClass = 454;    // Thump, thud
                pendingImpactScore = 99;
                lastImpactAt = millis();
                impactPending = true;
                Serial.println("[SND] (模擬) 撞擊聲");
            } else if (serialLine == "shout") {
                pendingDistressClass = 6;    // Shout
                pendingDistressScore = 99;
                distressPending = true;
                Serial.println("[SND] (模擬) 求救聲");
            } else if (serialLine == "sndreset") {
                lastSoundWakeAt = 0;
                lastImpactAt = 0;
                Serial.println("[SND] 已清除冷卻與佐證窗");
            } else if (serialLine == "snddebug") {
                soundDebug = !soundDebug;
                Serial.println(String("[SND] 診斷模式 ") + (soundDebug ? "開（每次推論都印前 3 名）" : "關"));
            }
#endif
            serialLine = "";
        } else if (c != '\r') {
            serialLine += c;
        }
    }
    if (recordingstate == 1 && previousRecordingState == 0) {
        // Change from 0 to 1
        digitalWrite(LED_BUILTIN, HIGH);
    } else if (recordingstate == 0 && previousRecordingState == 1) {
        // Change from 1 to 0
        digitalWrite(LED_BUILTIN, LOW);
        // ⚠️ 從這裡到本區塊結束(wait.wav → ASR → /voice → TTS 播放)全部是阻塞的,
        //    可能長達數十秒;這段期間主迴圈不會執行,按鈕**完全不會被讀取**。
        //    使用者在這段時間內按的任何一下都會被吃掉——「按了沒反應」多半是這裡。
        unsigned long blockStart = millis();
        Serial.println("[BTN] ⏸ 進入阻塞處理（ASR→/voice→TTS）,期間按鈕不會有反應");
        // 300ms + wait.wav 的播放時間,足夠讓 MP4 檔案收尾寫完
        delay(300);
        // 等待期間播放提示音,墊住 STT/TTS 的處理時間
        playPrompt("wait.wav");
        String text = sendAudioTpWhisper();
        Serial.println(text);
        if (text.length() > 0 && text != "null" && !text.startsWith("Connected to")) {
            // ASR 後的文字送雲端語音 Agent(不再直連 LLM):server 會做意圖分類、
            // 起 20 秒升級計時、必要時開派遣單,並同步回一句要立刻播的話。
            sendText(text);
        }
        // ⚠️ 診斷提示(目前刻意不修,先讓 log 呈現原始行為):
        //    若阻塞期間按鈕一直被按住,電平沒有變化 → buttonPressTime 仍停在很久以前,
        //    下一輪 millis()-buttonPressTime 必定 >= 2000,會「立刻」再開一次錄音。
        //    如果下面這行之後緊接著就出現 [BTN] → 開始錄音,而中間沒有 ↓按下 的邊緣 log,
        //    那就是這個成因。
        Serial.println("[BTN] ▶ 阻塞處理結束,共 " + String(millis() - blockStart)
                       + " ms;按鈕恢復反應（此刻電平=" + String(digitalRead(buttonPin)) + "）");
    }

    // Check if there are incoming bytes available from the server
    while (wifiClient.available()) {
        char c = wifiClient.read();
        Serial.write(c);
    }
    previousRecordingState = recordingstate;
    delay(10);
}

// ================= MQTT 下行 =================

// MQTT callback:只把 payload 複製進佇列就返回(不阻塞),實際發聲在主迴圈。
void onMqttMessage(char* topic, uint8_t* payload, unsigned int length)
{
    String msg = "";
    msg.reserve(length + 1);
    for (unsigned int i = 0; i < length; i++) {
        msg += (char)payload[i];
    }
    Serial.println("[MQTT] ◀ " + String(topic) + "  " + msg);

    if (cmdCount >= CMD_QUEUE_SIZE) {
        // 佇列滿:丟最舊的。急救場景下「最新的指示」比「補完舊的」重要。
        Serial.println("[MQTT] 佇列已滿,丟棄最舊的一筆");
        cmdHead = (cmdHead + 1) % CMD_QUEUE_SIZE;
        cmdCount--;
    }
    cmdQueue[(cmdHead + cmdCount) % CMD_QUEUE_SIZE] = msg;
    cmdCount++;
}

// 維持 MQTT 連線:斷線時依指數退避重連,重連後重新 subscribe 並發 online。
// 全程不阻塞主迴圈(用 millis 排程而不是 delay)。
void mqttPump()
{
    if (mqtt.connected()) {
        if (!mqttWasConnected) {
            mqttWasConnected = true;
            mqttConnectedAt = millis();
        }
        mqtt.loop();
        return;
    }

    // 剛剛還連著、現在斷了 → 把現場證據印出來。
    //   state=-3 (MQTT_CONNECTION_LOST)     底層 TLS 說「沒連線」
    //   state=-4 (MQTT_CONNECTION_TIMEOUT)  keep-alive ping 沒等到回應
    //   errno=128 (ENOTCONN)  對端把連線關了 → 往雲端那側查(IoT policy/憑證),不是韌體問題
    //   errno=11  (EAGAIN)    只是暫時沒資料,不該伴隨斷線;真出現代表另有成因
    if (mqttWasConnected) {
        mqttWasConnected = false;
        Serial.println("[MQTT] ✗ 斷線（這次連線撐了 " + String(millis() - mqttConnectedAt)
                       + " ms）state=" + String(mqtt.state()) + " errno=" + String(errno));
    }

    if (millis() < mqttNextAttempt) {
        return;    // 還沒到下次重試時間
    }

#if BACKEND_AWS
    // 沒憑證就別浪費一次 TLS 握手,直接講清楚原因(否則只會看到 rc=-2 一路重試)。
    if (!deviceCertReady()) {
        static bool warned = false;
        if (!warned) {
            Serial.println("[MQTT] ✗ 缺少 AWS IoT 裝置憑證:請把 device.cert.pem / device.key.pem "
                           "填進 secrets.h(見 secrets.h.example)。下行指令目前完全收不到。");
            warned = true;
        }
        mqttNextAttempt = millis() + mqttBackoffMax;
        return;
    }
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

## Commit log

2026-08-01 feat: 金孫收音機——長者近端 AI 陪伴與社區互助派遣系統
    Phase 1 閉環：感知 → 決策 → 行動 → 回報
    - firmware/ HUB8735 Ultra 韌體（按鈕錄音 → 雲端 ASR → /voice → MQTT TTS 播放）
    - cloud/ 語音多 Agent server、派遣狀態機、Supabase 資料層、ASR SageMaker
    - apps/ 家屬 App、志工 App、共用 packages（core / ui_kit）
    - admin/ 社工後台 dashboard ＋ Excel 匯出
    - docs/ 架構總覽與需求文件
    [back_panel_print.3mf, back_panel_print.step, back_panel_print.stl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]
2026-08-01 docs(deck): 提案簡報進版控，供隊友協作編修
    自 jinsun-proposal-deck/ 收錄至 deck/：純靜態 HTML 簡報
    （index.html + style.css + assets 框架 + img 情境圖），
    附 README 說明開啟與協作規則。.DS_Store 由 .gitignore 排除。
2026-08-01 feat: AWS 平行環境（與 Render/Supabase 完全獨立的第二套後端） (#2)
    * feat(aws): 建立與 Render/Supabase 對等的 AWS 平行環境後端
    與正式環境（Render + Supabase）完全獨立、不共用資料庫的第二套後端，
    四端與韌體靠建置參數切換，正式環境一行都不動。
    - API Gateway（HTTP API）單一 HTTPS 入口，6 條路由；/data/* 掛 JWT authorizer，
    /voice 與 /asr 落在 $default——長輩端是裝置身分，不該為了轉一句逐字稿去換 token
    - Lambda ×5：voice（六個 Agent）、data（三端資料 API＋角色授權）、
    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
2026-08-01 feat(deck): expand problem scale data and refine narrative
    - Update hero headline from "社工卻在銳減" to "能到場的人卻不夠" for clearer problem framing
    - Add statstrip with three key statistics (20.1% elderly population, 70 万 isolated seniors, 93% lack emergency equipment)
    - Revise problem scale section heading to emphasize "70 萬人獨居" demographic
    - Update elderly population chart with actual 2025 data (467 万人・20.1%) and 2070 projections (697 万人・46.5%)
    - Recalibrate population funnel with government statistics: 467 万 → 70 万 → 35 万 → 7 万 units
    - Replace speculative market estimates with actual government budget allocation (62.5 billion for 70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
2026-08-01 docs(deck): open-slide 簡報工作區，含 AWS 部署說明投影片
    以 React component 撰寫投影片的 open-slide workspace（slides/<id>/index.tsx
    default-export 一組 page），另附 .agents/skills 的撰稿與主題規範，
    .claude/skills 以 symlink 指過去共用同一份。
    目前有兩份 slide：getting-started（範本）與 aws-deployment。
    node_modules/ 與 dist/ 由 my-slide/.gitignore 排除，不進版。
2026-08-01 fix: 角色走查修正 + 派遣即時性 + 到門口播報
    四種角色（家屬/志工/社工/長輩）走過整條閉環，修好會誤導或不便的地方：
    - 社工後台：確認窗內未開單長輩不再顯示綠色「已完成」（依 elder.severity）、
    手機版也列出、鈴鐺數套用「只看我的」過濾；Excel 補結案處置/現場備註欄、
    save() 失敗不再誤報已下載；地圖過濾未定位長輩並提示 N 位未定位。
    - 家屬 App：配對綁定失敗不再假成功；Wi-Fi 掃描逾時給「重新搜尋」；
    提醒本地持久化(shared_preferences)+刪除可復原+文案不再誆稱即時同步收音機；
    通知權限橫幅可點重試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
2026-08-01 feat(deck): add slide 15 and refine product messaging
    - Increment total slide count from 14 to 15 across all footer references
    - Update child user pain point with new medication reminder feature in solution section
    - Refine SOS button description to emphasize voice capability over manual input
    - Clarify hardware privacy messaging: "影像不上傳、不自動保存" replaces "影像永遠留在晶片裡"
    - Enhance talk key section header and add privacy distinction from smart speakers
    - Detail AI chip image handling: local processing, no auto upload, authorization-required access
    - Improve product copy clarity for elderly users on screen-free operation
    - Expands solution offerings to include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
2026-08-01 feat: 吃藥提醒手動下發（家屬按鈕 → MQTT → 收音機發聲）
    - server: POST /remind → enqueue 扇出 → MQTT jinsun/{serial}/cmd（真收音機）＋長輪詢
    - 家屬 App: 提醒頁每筆多「立即提醒」🔊 按鈕 → reminder_push 服務打 $SIM_BASE/remind
    - 長輩收音機網頁: 新增 /commands 長輪詢，收到 type:speak 就念出來（與模擬器一致）
    - deploy: setup-server-cloudfront.sh 給 http-only ALB 一個 https 前置，
    解決 https 網頁呼叫 http server 的 mixed-content；README 補 runbook
2026-08-01 feat: Enhance local sound event detection and refine TTS integration
    - Implement local sound event detection using NPU and YAMNet for improved responsiveness to distress signals.
    - Add functionality to trigger recording via voice commands in addition to button press.
    - Introduce a structured response mechanism for detected sounds, including thresholds for distress and impact sounds.
    - Update TTS integration to support both ATEN (Taiwanese) and Amazon Polly (Mandarin) models, with fallback mechanisms.
    - Document changes in README.md, including detailed explanations of sound detection logic and troubleshooting tips for MQTT connectivity issues.
    - Address known limitations and provide compilati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
    [HUB-8735-Ultra-ASR-TTS.ino]
2026-08-01 feat: 將按鈕觸發錄音時間從 2 秒調整為 1 秒
2026-08-01 fix: 社工後台消閃爍 + 到場播報改「請待在原地」
    - SupabaseBackend：5 個 loader（elders/events/tasks/volunteers/messages）加
    rows JSON 內容指紋去重，內容沒變就不 emit。8 秒保底輪詢與多路 Realtime 回呼
    常帶回一模一樣的資料，原本每次都 emit → 三端 StreamBuilder（含 FlutterMap）
    整片重繪、地圖磚重載 → 畫面閃爍。AwsBackend 本來就靠 /data/version 指紋，
    這次把 Supabase 這條補齊。
    - 到場語音：拿掉所有「開門／到門口／敲門」措辭——獨居長輩（尤其剛疑似跌倒）不該
    被叫去起身應門。緊急單改念「志工○○已經到了！請待在原地不要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
2026-08-02 feat: Add OpenAI-compatible ASR endpoint via Lambda for SageMaker integration
    - Implemented a new Lambda function (`jinsun-asr-openai`) to serve as a proxy for the SageMaker `breeze-asr-26` endpoint, allowing it to be accessed via OpenAI's REST API format.
    - Updated deployment scripts to include the new ASR Lambda function and its API Gateway routes.
    - Enhanced documentation to reflect the new ASR capabilities and integration details.
    - Modified firmware to switch ASR API key and endpoint to the new Lambda function, ensuring compatibility with existing hardware.
    - Updated handoff and integration documents to include new resources and usage instructions.
    [HUB-8735-Ultra-ASR-TTS.ino]
2026-08-02 docs(deck): add visual assets and architecture diagrams for pitch presentation
    - Add role-based UI mockups for elder, family, volunteer, and worker applications
    - Add 10 comprehensive system architecture diagrams covering deployment, data flow, and emergency escalation
    - Add development and real-world deployment comparison assets
    - Add persona and product design documentation screenshots
    - Create complete pitch slide component with integrated visual assets
    - Enhance presentation narrative with technical and user journey visuals
2026-08-02 docs(deck): add hardware wiring diagram and optimize persona assets
    - Add hardware wiring SVG diagram for HUB8735 ultra and MAX98357A I2S amplifier
    - Optimize and add 3x4 aspect ratio variants for all persona images (child, elder, volunteer, worker)
    - Update slide presentation to reference new hardware architecture visualization
    - Improve visual asset organization for pitch deck consistency
2026-08-02 fix: 對話文字送不出去 + 社工後台地圖載入灰塊
    - chat：_send 沒有 try/catch，且在 await 前就清空輸入、把 _sending 設 true。
    一旦送出失敗（如 AWS token 過期／網路抖動），文字已被清掉、畫面不報錯，_sending
    永遠卡 true → 送出鍵之後完全沒反應（語音輸入完想送卻送不出去）。改為 try/catch/
    finally：只在成功後清空、失敗保留文字並提示、_sending 一定歸位；送出中顯示轉圈並停用。
    - admin 服務地圖：圖磚載入前（約 1~2 秒）改用畫布暖底，取代 flutter_map 預設深灰——
    初次載入時「派遣監控」下方不再閃一塊突兀的灰色大區塊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
2026-08-02 docs: Update AWS architecture documentation with new service integrations and flow details
    - Added links to architecture diagram and Q&A document.
    - Updated flowchart to reflect changes in service connections, specifically for SGM and MCU.
    - Revised AWS services table to include new Lambda function for OpenAI compatibility and updated SageMaker ASR status.
    - Clarified usage of various AWS services and their roles in the architecture.
    - Adjusted sequence diagram to indicate completed integrations and removed references to unused services.
